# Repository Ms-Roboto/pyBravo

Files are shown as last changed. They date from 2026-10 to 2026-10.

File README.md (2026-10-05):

## In memory of Ben Shamah

This project exists because of Ben Shamah (1973–2018).

Ben studied mechanical engineering at UC San Diego and robotics at Carnegie
Mellon, where he worked on NASA-funded robots built to explore other planets.
He brought that work back down to the bench, joining Velocity11 to build
machines that would speed up medical research — and it was there, with
colleagues including Brad Nelson, Dave Assmusen, and Chris Shaw, that the Bravo
was born. He later co-founded BioNex Solutions and led its technical side.
People who worked with him describe someone quiet and generous, who liked
puzzling out hard engineering problems and liked helping other people solve
theirs even more. He died of cancer in 2018, at 45.

The Bravo is a genuinely good machine, and a lot of them are still running. The 
goal here is to let the hardware Ben helped design join the open source 
community.

---

# pyBravo

An open-source Python driver and web control system for Bravo liquid handling
robots. It connects to the instrument over Ethernet or serial, exposes every
motion and liquid-handling operation through a REST API and a browser UI, and
runs complete pipetting workflows. It has a full simulation mode so you can
build and test protocols without touching hardware.

```bash
git clone https://github.com/kelsorj/pyBravo.git
cd pyBravo
./scripts/start_pybravo.sh      # Windows: scripts\start_pybravo.bat
```

Then open <http://localhost:8000>. Out of the box the server runs against a
simulated robot, so this works on any machine.

> [!WARNING]
> This software drives a physical robot with enough force to break labware,
> crush a pipette head, or injure a hand. Read
> [docs/safety.md](docs/safety.md) before you connect to real hardware, and
> dry-run every new protocol in simulation first.

https://github.com/user-attachments/assets/48de0bf6-f5a1-409d-ab84-00fcac42d9b6

---

## What it does

- **Direct hardware control** — connect, initialize, home, move, and jog every
  axis, with live position and state streaming over WebSocket.
- **Liquid handling** — aspirate, dispense, and mix, with configurable liquid
  classes and pipette techniques.
- **Tips and labware** — tip pickup and ejection, an editable labware catalog,
  gripper pick-and-place, and lid handling.
- **Visual workflow designer** — build protocols as a node graph or describe
  them in a chat that draws a draft graph; review chat drafts in Protocol
  Assistant before simulation and instrument execution.
- **Protocol Assistant** — turn text or PDF protocols into reviewed workflows
  with a local model, resolve missing details, strictly simulate, and reuse
  approved procedures and setups. The [Bravo Capability Manifest](docs/bravo-capability-manifest.md)
  publishes the active instrument's model-selectable planning options and
  compatibility constraints. See [the guide](docs/protocol-assistant.md).
- **Deck management** — a 3×3 deck model with per-location teachpoints, and
  obstacle-aware Z clearance when the gripper carries plates between locations.
- **3D digital twin** — watch a URDF model of the robot mirror the real
  machine's position in real time.
- **Simulation mode** — the full motion, liquid-handling, and workflow stack
  runs with no hardware attached. The optional accessories below are the
  exception: they talk to real serial ports.
- **Optional extras** — camera-based deck verification, barcode reading,
  orbital shaker control, and an LLM-assisted protocol drafter.

## Supported hardware

| Instrument generation | `controller_type` | Connection |
|---|---|---|
| Darwin-generation Bravo | `darwin_native` | TCP, port 7613 |
| Agile 7612 Bravo | `agile_7612` | TCP, port 7612 |
| Bravo SRT | `agile_srt` | TCP, port 7612 |
| Legacy Agile Bravo | `agile` | Serial, or TCP port 10000 |
| No hardware | `simulation` | — |

Details and wiring notes are in [docs/hardware-setup.md](docs/hardware-setup.md).

## Documentation

Start with the [documentation index](docs/README.md). The most-used pages:

| Page | What it covers |
|---|---|
| [Installation](docs/installation.md) | Requirements and install paths for macOS, Linux, and Windows |
| [Quickstart](docs/quickstart.md) | First run in simulation, then your first real move |
| [Hardware setup](docs/hardware-setup.md) | Networking, finding your robot, profiles, teachpoints |
| [Safety](docs/safety.md) | What can go wrong and how to avoid it |
| [User guide](docs/user-guide.md) | The web UI, end to end |
| [Workflows](docs/workflows.md) | Building and running protocols in the designer |
| [Configuration](docs/configuration.md) | Profiles, environment variables, config files |
| [API reference](docs/api-reference.md) | Every HTTP and WebSocket endpoint |
| [Architecture](docs/architecture.md) | How the codebase fits together |
| [Protocol specification](docs/protocol-spec.md) | The instrument wire protocols |
| [Bravo Capability Manifest](docs/bravo-capability-manifest.md) | Versioned instrument options for protocol-planning models |
| [Troubleshooting](docs/troubleshooting.md) | Symptoms, causes, fixes |
| [FAQ](docs/faq.md) | Common questions |

## Requirements

Python 3.11 or newer. The launcher scripts use [uv](https://docs.astral.sh/uv/)
when it is available, which installs a suitable Python and all dependencies
automatically; see [Installation](docs/installation.md) for the alternatives.

## Contributing

Contributions are welcome — see [CONTRIBUTING.md](CONTRIBUTING.md) for how to
set up a development environment, run the tests, and submit a change. Please
also read the [Code of Conduct](CODE_OF_CONDUCT.md). To report a security
issue, follow [SECURITY.md](SECURITY.md).

## License

pyBravo is an independent project. It is not affiliated with, endorsed by, or
supported by Agilent Technologies, Inc. Product names are trademarks of their
respective owners and are used only to identify the hardware this software
runs. See [NOTICE](NOTICE) for the full trademark statement.

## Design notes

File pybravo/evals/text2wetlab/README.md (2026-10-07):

# Text2WetLab OT-2 benchmark adapter

This package generates an Opentrons OT-2 Python API protocol from each task's
written instruction. It uses the configured OpenAI-compatible **local** model
server, validates the Python entry point, and runs `opentrons_simulate` when
that command is available. It never invokes Bravo or Opentrons hardware.

```sh
.venv/bin/python -m pybravo.evals.text2wetlab \
  --task-dir /path/to/task \
  --instruction-file /path/to/task/instruction.md \
  --simulator-command /path/to/opentrons_simulate \
  --event-logger /path/to/pinned/runlog.py
```

An optional `--paper-file` adds task-supplied scientific source text to the
model prompt. For a paper with clear Methods and Results headings, the adapter
passes the complete, verbatim Methods section instead of unrelated article
sections; its trace records the full-source and excerpt digests and line span.
If the section cannot be identified completely, the full supplied text is
preserved. The adapter also reads the installed simulator's labware definitions
and any task-supplied custom JSON to give the model exact well counts and
column layouts. These catalog facts do not supply experimental volumes or
reagents.

Model endpoint and alias default to the existing
`PYBRAVO_DRAFTER_BASE_URL` and `PYBRAVO_DRAFTER_MODEL` settings; the CLI also
accepts `--model-base-url` and `--model`. The benchmark CLI defaults to a
300-second model timeout, 16,000 output tokens, and no automatic repeat of a
timed-out HTTP request. `--model-timeout` and `--max-output-tokens` can adjust
those bounds.
When a task supplies custom Opentrons labware JSON, place the pinned files in
a directory and pass `--labware-dir /path/to/labware`. The adapter passes that
directory to both the CLI simulator and structured logger; the generated
protocol only names the labware in `load_labware()`.

The task directory receives `protocol.py` only after static validation and,
when the simulator is installed, a passing simulation. It always receives
`generation_trace.json` after an attempted generation. Statically valid but
rejected sources remain as `candidate_attempt_N.py` files, with exact paths in
the trace; unchanged repeats skip another simulator run. A trace marked
`static_validated_only` means no simulator was found; it is not a simulation
pass. A `simulated` trace also requires structured action-event validation:
each tip may touch one specimen well before disposal, while a reservoir may
feed multiple wells of an otherwise destination-only plate. A tip may not
aspirate from two distinct reagent-stock wells, and P20/P300/P1000 liquid
strokes must meet the documented OT-2 GEN2 working ranges. For an on-deck
heat-shock/recovery instruction, a timed hot-block pulse must end before
serial recovery pipetting begins. Simulation does
not establish that the protocol satisfies a scientific rubric or is safe to
run on physical hardware.

## Optional phased ActionPlan experiment

`scripts/experiment_text2wetlab_phased_action_ir.py` is an isolated alternative
for protocols too long to fit in one local-model response. The first Qwen call
authors the fixed OT-2 setup, cited initial-supply claims, and a short ordered
stage outline. A separate call authors the actions for each stage. Every
action cites an exact pinned task or paper line. The merger only concatenates
accepted stage actions; it inserts no experimental steps.

Each prefix is compiled against the installed OT-2 catalog, statically checked,
simulated, passed through the pinned event logger and event-safety check, and
audited for tip use and per-well material balance before the next Qwen call.
Unknown starting volumes stay unknown and are reported for review. A failed
prefix stops the experiment; the raw Qwen response and failure remain in the
output directory. The complete merged plan then runs the existing pinned lint,
simulator, event, and local science gates. `official_score` is always null;
Harbor's private scoring is not run. This path never controls hardware or
changes the production generator. The setup trace also lists procedural-looking
source lines omitted from stage citations for review; citations alone never
certify scientific completeness.

```sh
.venv/bin/python scripts/experiment_text2wetlab_phased_action_ir.py \
  --task opentrons-rna-extraction \
  --simulator /path/to/opentrons_simulate \
  --output-dir /tmp/text2wetlab-rna-phased
```

An exact earlier model setup can be resumed with `--saved-setup
/path/to/qwen_setup.json` only when its sibling trace matches the pinned task,
source digests, and raw response digest. `--max-stages` caps further local calls.

## Optional per-well material ledger

`material_ledger.audit_material_flow()` can inspect the trusted logger's
ordered `events` array without changing the generator or benchmark runner.
Pass `WellRef` → `InitialWell` entries for known source volumes and confirmed
empty destinations, plus `WellLimit` entries for catalog capacity or a
scientist-specified final reaction volume. `StageBoundary` and
`stage_targets_ul` let a reviewer check a prepared mixture *before* it is
consumed; this catches a duplicated preparation that a final-volume-only check
would miss. The result retains source-labelled component amounts, final
per-well volumes, ordered snapshots, and separate error/warning codes.

Missing starting volumes remain unknown, and missing destinations are not
silently assumed empty. The logger records only a multichannel anchor well;
callers must provide a geometry-backed `well_resolver` that returns one
`WellRef` per physical channel before multichannel flow is counted. Exact
component amounts for a partial withdrawal from mixed material require an
explicit mix event; a full withdrawal still conserves its total components.
This ledger does not establish reagent identity,
mixing quality, concentrations, or a protocol's scientific correctness. It is
currently a standalone audit utility; it does not change official scoring.

`material_plan_bridge.targets_from_accepted_plan()` can supply ledger targets
from an accepted local-model `PlanningResult`. Because `OT2Plan` has no
destination-well field, each `TargetBinding` must cite the exact vessel/well
and the corresponding reaction volume in the task or paper. For a generated
intermediate, it also needs a matching generated `DeckSource` and a trusted
stage-to-event boundary. Unlinked quotes, ambiguous reactions, and missing
boundaries become `review_gaps`; they never create a target by inference.
Callers can pass the resulting limits, stage targets and boundaries into the
ledger, along with independently confirmed initial volumes and geometry.

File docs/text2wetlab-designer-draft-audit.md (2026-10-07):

# Text2WetLab Designer draft audit

The seven saved Text2WetLab adaptations are local-Qwen-authored **native Designer graphs**. They open with `/designer?workflow=<id>` and use ordinary LiteGraph primitive node types. All seven returned HTTP 200 from the local `/api/workflows/{id}` endpoint on 2026-10-07 with their draft marker and node graph intact. That proves the diagrams can be inspected; it does not prove that their nodes form a valid, simulatable Bravo procedure. Designer now permits software rehearsal of native generated drafts on an isolated simulator, with catalog preflight and a stop on any task error. Hardware Execute remains blocked while `protocol_generated_draft` is true, and rehearsal does not qualify or approve a method. This marker must not be removed to work around validation.

This audit inspected the saved workflows under `~/.pybravo/workflows` against the active `/api/protocols/context` on 2026-10-07. The profile was `04-91-62-CF-7B-B0 / HT_384_D_70`. It offered one execution-ready rack/tip pair: 384-position `lw-4914769d0af7` with independent `st_10ul` tips. Five active classes used `st_10ul`. Two `st_30ul` classes existed, but the context did not offer an execution-ready matching rack. Catalog availability is still separate from confirmation of physical loading or liquid-method qualification.

For unresolved drafts, Designer also offers **Walk through draft** through
`POST /api/workflows/{id}/walkthrough`. This separate, nonexecuting viewer
replays connected task order and retracted head hovers over taught deck
locations. It does not pick tips, move plates, perform liquid strokes, or
validate collision geometry, liquid methods, or scientific completeness.
Every event and response reports `validation_passed=false` and
`qualification_granted=false`. Unknown class references remain visible, and
the strict `/simulate` and hardware `/execute` gates remain in force.

Designer now scopes its class dropdown to the active machine/head (or an
explicit persisted `protocol_simulation_target`). A proposed virtual target
must use catalog head/tip compatibility, capacity, and a known tip length;
it changes only a copied simulator profile. The installed instrument and
hardware class records remain unchanged. Saving retains prior draft findings
with a stale-validation marker instead of displaying a false zero-check result.

| Task | Saved graph | Main blockers for this active Bravo profile |
| --- | --- | --- |
| A1–A12 transfer | [7 nodes](http://127.0.0.1:8000/designer?workflow=10c25e05-4f13-4da6-be02-45f8c233e957), including a 12-iteration Loop | Fixed tip-cell pickup inside the Loop; source and destination labware absent from the proposed deck; 100 µL transfer exceeds the ready ST10 tip capacity; proposed class/rack unavailable. |
| Split 200 µL | [9 nodes](http://127.0.0.1:8000/designer?workflow=b7735e14-79f1-47b2-8560-5469422a0e64) | Two 100 µL liquid actions exceed the ready ST10 tip capacity; proposed 96-position rack and class are unavailable for this head. |
| AMPure cleanup | [42 nodes](http://127.0.0.1:8000/designer?workflow=e41685a4-f7b9-459b-92f2-46c6f45085bd), with separate aspirate/dispense primitives and manual magnet stages | No proposed deck entries at all; liquid locations and tip supply cannot resolve. Several 40–200 µL actions exceed the ready ST10 capacity, and the generic class is unavailable. |
| Colony PCR | [11 nodes](http://127.0.0.1:8000/designer?workflow=236647b7-704b-4b9c-a7cf-1a9339d211d1) | Full 384-channel head mode is proposed against 96-well labware; sample mapping and tip isolation are unproven; proposed rack/class unavailable. |
| E. coli heat shock | [13 nodes](http://127.0.0.1:8000/designer?workflow=c5c9055e-043d-4ad4-b467-9c72d0eca7a1), including external-stage handoffs | Saved review issues include head/plate footprint, missing executable well mapping, and unavailable rack/class. The independent re-audit needs the exact source paper supplied at generation time to verify its saved SHA-256; the default dataset source does not satisfy that digest. |
| Golden Gate | [26 nodes](http://127.0.0.1:8000/designer?workflow=dc69afcd-3825-4340-81ca-3ed769695e6d) | Liquid nodes use a descriptive `wells` string such as `A1:G1`; the Bravo executor reads executable `anchor` and head mode instead. Several transfers exceed ready ST10 capacity; the proposed rack/class are unavailable and sample mapping is unproven. |
| RNA extraction | [25 nodes](http://127.0.0.1:8000/designer?workflow=3530efd6-76b7-4204-94ce-52a9e0d35638) | Full 384-channel mode is aimed at 96-well labware; 48-sample coverage, tip isolation, and elution stage are unproven; proposed rack/classes unavailable. |

These are independent **Bravo** problems. The benchmark's required OT-2 labware, pipettes, modules, and deck slots do not establish matching Bravo consumables or positions. The current profile cannot complete the larger-volume tasks using its one ready ST10 pairing. Switching to or adding a verified head, rack, tip, and method is a hardware-catalog decision; silently splitting a required operation or renaming a method would change the scientific procedure.

## Generic path from a diagram to a usable workflow

1. Have the local model author an ordered, typed scientific action plan with source/destination wells, volumes, sample identities, tip-isolation groups, and external-stage handoffs. Store exact source citations and unresolved experimental facts. Its `wells` list is evidence of intent, not a command to the Bravo executor.
2. Resolve each action against an explicit machine profile and current deck inventory. Require an execution-ready head–tip–rack–liquid-class combination and labware geometry; compare every single stroke with effective capacity. Report unsupported actions instead of creating runnable-looking nodes.
3. Lower resolved actions deterministically to the existing `tips/TipsOn`, `liquid/Aspirate`, `liquid/Dispense`, `tips/TipsOff`, plate, wait, and manual primitives. Expand or parameterize repeated operations so the runtime receives valid `anchor` and head mode for each iteration and fresh-tip selection cannot repeat a spent cell. Preserve the action-to-node provenance.
4. Validate the resulting DAG's topology, per-iteration material and tip ledger, live deck transitions, method settings, and external handoffs. Run strict simulation against the same pinned profile and graph revision. Only a scientist-reviewed, simulation-passing revision should become executable.

To reproduce a **read-only** audit, run `.venv/bin/python scripts/repair_text2wetlab_designer.py --output-dir /tmp/pybravo-text2wetlab-designer-audit`. It writes a report under `/tmp` and never contacts Qwen unless `--run` is supplied. Pass `--ecoli-paper` with the exact original paper if auditing that draft's source provenance. The saved draft remains unchanged.

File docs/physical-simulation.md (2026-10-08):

# Physical rehearsal with SuperDex

Designer **Simulate** and Protocol Assistant strict simulation now run the native
Bravo primitive tasks on an isolated simulation controller. Each controller
motion is checked before positions change. The physical scene uses
[SuperDex Physics](https://projectsuperdex.com/physics/docs/overview/) with closed
Bravo URDF tool/gripper collision meshes, calibrated deck planes, catalog
labware envelopes, and carried plate envelopes. The separate **Walk through
draft** action illustrates order and does not grant physical clearance.

Every Designer **Simulate** action uses the same guarded executor, whether the
protocol was built by hand, imported, loaded from the library, generated by the
assistant, or previously reviewed. Protocol Assistant uses that executor too.
There is no per-protocol physics opt-in. Both entry points call
`WorkflowExecutor.for_simulation(...)`, which requires physical checks, stops on
task errors, and disables the old animation-before-task path. Failed or
unsupported tasks cannot be ignored to obtain a simulation pass.

For a Python caller, construct an isolated `Bravo` with `mode="simulation"`
(copy the hardware profile first), then use
`WorkflowExecutor.for_simulation(bravo, graph, deck_config=deck, on_event=handler)`
and await `execute()`. The ordinary constructor remains the native execution
interface; the simulation factory refuses options that disable required checks.

## Results and saved protocols

A simulation passes only when its final completion event contains a current
SuperDex report with no error and valid checked-move, pose, and contact-query
counts. The report includes
`contract_version: pybravo.superdex-rehearsal.v1`, separately from the native SDK
version. An early scene-ready event is not evidence of completed execution.
Protocol Assistant binds the result to the saved workflow and context hashes;
older passes without this evidence require another simulation. Historical
scientist decisions and approval records are retained for audit.

Changing the robot collision assets invalidates saved simulation evidence.
Changing them during a rehearsal stops that run before another motion is
accepted, so a report cannot silently combine different model versions.

Designer displays the failed task, colliding bodies or missing geometry, and
rejected coordinates. Workflows containing only waits/manual instructions report
that no native motion was checked. **Replay simulation** on a saved compiled
preview replays its recorded events; it does not perform another physical run.

## Installation

In the repository environment, using Python 3.12 on a supported platform:

```sh
python -m pip install -e '.[physics]'
```

The deployment used for this change has SuperDex 1.0.0 installed. Its current
native wheels support macOS arm64, Linux x86_64 and Windows amd64. A missing SDK,
invalid mesh, missing teachpoint or missing collision dimensions causes an
explicit failed rehearsal. It never falls back to unchecked motion. Read-only
planning and the control panel can still load without the optional SDK.

## Planning and tip state

`GET /api/workflows/{workflow_id}/mechanical-readiness` checks the saved native
graph against the selected head and catalog without motion. It reports missing
deck bodies, incompatible selections, and repeated tip-lifecycle errors. This
is a static planning check; strict simulation still checks the actual expanded
loops, runtime inventory, liquid classes and commanded motion.

The native ledger keeps **fresh**, **spent**, **occupied**, and **empty** wells
separate. A returned tip occupies a hole but is spent and cannot be picked as
fresh. The ledger follows moved racks. Only an explicit restock/load resets
fresh supply. In a repeated fresh-tip workflow, the model must plan a clean
supply and a separate compatible empty return rack or configured waste. A
catalog rack is not evidence of loaded inventory. A fixed repeated pickup/return
anchor is rejected; the native runtime also stops on spent pickup, exhaustion,
or occupied return wells. A dedicated source can return its final spent set
to its original rack when that rack will never be used again.

Explicit partial inventories are preserved for catalog racks whose underlying
shape is an SBS plate and whose base class is a tip box. They are not replaced
with a full rack, and the recorded inventory follows the rack when it moves.

The drafter now preserves each proposed rack's `tipbox_fill_state`: clean
supply is full and the separate spent-return box is empty. These are proposed
loading instructions, not evidence of physical inspection. For a gripper-equipped
Bravo, include a visible native DockGripper before tip handling. The native
regression found an undocked finger hitting a rack on a later single-tip pickup;
the same twelve-cycle path clears after docking.

## What is checked

- Axis limits and finite positions; sampled interpolation of every actual
  native controller command, including endpoints and positions between them.
- Tool/gripper contacts with deck pads and labware. A low path through a
  neighboring stack fails even when both endpoints are clear.
- Carried plate envelopes during verified native PickPlace stages, including
  Stack, Destack, Mount and Unmount. Their poses follow the gripper calibration
  and move to their new deck locations after release.
- Mounted tip axes against well centers and bottoms, using recorded tip length,
  well grid, depth and diameter. Intentional rack seating and flange contact
  have narrow task-specific allowances; they do not suppress neighbor contacts.
- Recorded lid exterior envelopes against the moving tool and mounted tip
  segments. A covered liquid target remains inaccessible; native well-access
  checks are preserved rather than commanding an approach through the lid.
- Simulated stack-height scan approach and descent to the catalog-derived stack
  surface. Plate count comes from the virtual deck; optical sensor response and
  force/contact sensing remain unqualified. The scan preserves the modeled
  plate identities for subsequent tasks.
- Drift of profile calibration, teachpoints or labware metadata during the
  rehearsal. Reports pin robot assets, profile and initial deck geometry by
  SHA-256 and retain the failed task, bodies, penetration and sampled pose.

The native SDK runs on one dedicated owner thread. Initialization and disposal
do not freeze the UI event loop; task worker threads synchronously wait for each
collision guard. A rejected multi-axis move leaves all controller positions
unchanged. Errors stop the rehearsal and highlight the task in Designer.

## Limits of a clear result

Designer opens a rotatable obstruction preview for covered-plate failures.
It highlights the reported deck position and stack item, with nearby labware
for context. **View obstruction** reopens the picture; **Edit deck position**
opens the affected setup. Closing the view disposes its renderer, including
assets that finish loading later.

The CellVis 384 plate has a manufacturer-dimensioned lid envelope based on the
[official drawing supplied by the user](media/cellvis-384-plate-lid-dimensions.png):

| Dimension | Millimetres |
| --- | ---: |
| Plate length × width | 127.6 × 85.6 |
| Uncovered plate height | 14.33 |
| Lid length × width × height | 127.15 × 85.05 × 10 |
| Covered assembly height | 16.8 |
| Seated lid bottom above plate base | 6.8 (16.8 − 10) |

Rendering and collision checks use the same centered exterior box. It includes
the hollow interior and undimensioned corner chamfers, so it is conservative;
it can reject close approaches that a detailed shell would clear. The drawing
does not specify wall thickness, internal clearances or grasp calibration.
It therefore supports exterior obstacle checking, not robotic lid removal or
replacement. Existing grasp and departure calibration values are not inferred
from the picture. Delid/Relid remain blocked pending a supported shell/contact
model and verified state transitions.

A liquid task aimed at the covered CellVis plate stops with a dimensioned
well-access diagnostic before its approach is commanded. That picture has no
rejected robot pose. A sampled tool or tip collision with a modeled lid reports
the rejected pose and envelope instead. Unknown lids and seals still stop at
setup and retain the explicitly illustrative preview. None of these views
changes the workflow or marks the lid removed.

The default spacing is 0.5 mm with a 0.05 mm penetration reporting threshold.
These are sampled geometric checks, not certified continuous collision
detection. They interpolate each commanded move in axis space; firmware timing
may differ. The 384ST head uses its collision CAD mesh; other head housings use
a conservative envelope because separate CAD exports are unavailable.

Plate envelopes include solid flanges and approximate well access. Detailed
tip taper, grasp force, fluid retention, calibration accuracy, frame/gantry
self-collision and wet-lab performance are not qualified. Lid operations,
seals, lids without recorded envelopes, and accessories without collision geometry fail
closed. Passing checks does not authorize hardware execution or qualify a
liquid method. The saved revision's method review and release remain required.

Some deployed tip-box records have zero or missing hole diameters. Those records
remain incomplete: static Designer preflight identifies missing return-rack
diameters before motion. It also rejects liquid tasks aimed at a known tip rack
or tip-waste receptacle. Workflows with dynamic locations or deck-changing tasks
retain native checks against the actual labware present at each step.
The simulator does not replace unknown catalog measurements with guessed
clearances. Native tip-cycle regressions use explicitly labeled synthetic
mechanical fixtures; they do not qualify the deployment's rack dimensions.

The deployed `lw-4914769d0af7` ST10 rack's previously missing aperture diameter
was recovered as **3.3 mm** from its existing
`labware/editor_assets/lw-4914769d0af7/ST_Tip_Box.gltf` CAD asset on 2026-10-07.
All 384 circular apertures agree within 0.000003 mm in the exported mesh. Asset
SHA256: `0a9dfef973ae4266042b73614536132d693dc592135c3eccb270d6aa2b082fb5`.
The catalog description records this as model-derived geometry, not a physical
measurement or hardware qualification. Rack height and teachpoint offsets were
preserved. A separate same-plate test workflow uses rack 1 for pickup, CellVis
plate 2 for aspiration and dispense, and empty rack 3 for spent-tip return.

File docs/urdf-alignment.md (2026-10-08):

# URDF head alignment (3D view only)

The original renderer-only calibration below is historical context. The later
[gripper assembly correction](#gripper-assembly-datum-october-2026) updates the
shared URDF used by both the viewers and SuperDex; it does not change commanded
positions or hardware teachpoints.

> **Status: all three axes are fixed.**
>
> - **Z — done.** The head was drawn one teach-tip too low. Corrected via the
>   live `head.teach_tip_length_mm`; see "The Z axis" below.
> - **X and Y — done.** Fixed as measured gantry datums in `JOINT_AXIS_MAP`
>   (`xaxis: 182.64`, `yaxis: 2.3`), not by moving the drawn tips; see "The X/Y
>   datum" below. Two earlier attempts moved the tips instead of the gantry and
>   were reverted — "Two alignments, not one" below explains why that can never
>   work, and remains the most useful thing on this page.
>
> All of this is cosmetic. Real motion is unaffected.
>
> **Confirmation recording:**
> [docs/media/tips-on-off-simulation.mov](media/tips-on-off-simulation.mov) — a
> simulate run captured after the fixes: the head descends aligned with the
> box, the tips leave the box and attach at the bottom of the press, ride up
> with the head, and are released into the destination box at the eject.
> (GitHub plays committed videos from the file's blob page; open the link.)

> **Scope: the 3D view, and nothing else.**
>
> Real motion is correct. Tips on and tips off work on hardware in full, row,
> column and partial modes, on both 96 and 384 heads. The commanded positions,
> the teachpoints, and the geometry in `pybravo/deck/geometry.py` and
> `pybravo/head_mode.py` are therefore **authoritative and out of scope**.
> Nothing described here may change a commanded position, and no change made
> for the reasons in this document belongs anywhere except
> `frontend/src/robot-scene.js`.
>
> If a proposed change to the 3D view would require editing anything under
> `pybravo/`, the proposal is wrong.

## The problem this existed to solve

In the 3D view the head's barrels were drawn a couple of columns away from the
wells they were actually over — worst at the edge of an empty tip box, where
the tips visibly hung off the end.

## The X/Y datum — diagnosed and fixed

The error was in the gantry's visual datum, not in where the tips sit on the
head. Measured with the head-tip array (placed from the head mesh) against the
rendered wells, at four commanded poses spanning 99 mm of X travel and both
deck rows:

| | error, every pose |
|---|---|
| X | **−10.40 mm** (≈2.3 columns), constant |
| row (robot Y) | **+2.40 / +2.19 mm** per location (mean ≈ half a pitch) |

Constant across the whole span in both axes — a datum error, not scale. Both
derivatives measured exactly 1 mm world per commanded mm, so the correction is
a pure `homeOffset` shift in `JOINT_AXIS_MAP` (`frontend/src/robot-scene.js`):
`xaxis` 193.04 → **182.64**, `yaxis` 0 → **2.3**. After the change the residual
is 0.00 mm in X and ±0.11 mm in row at all four poses — the ±0.11 is the two
locations' real taught difference, which a flat model deck cannot represent.

Why this works where the two reverted attempts could not: `homeOffset` moves
the **whole gantry chain** — head mesh, attached tips, and gripper together, as
on the real machine (they share one carriage; confirmed against the URDF joint
tree, where both hang under `ygantry` ← `xgantry`). The tips↔mesh relationship
is preserved by construction (the tips move with their barrel mounts), and
deck pads and labware are static children of the base and do not move. The
earlier attempts moved only the drawn tips, which can satisfy tips↔labware or
tips↔mesh but never both.

The remaining per-location ±0.1 mm class of residual would only be removable by
modelling the deck's taught Z/XY variation, which is not worth it for a
visualization.

This document is the definition the renderer should use instead.

## The invariant

> When the robot is commanded to a position, the **rendered** head's A1 barrel
> must appear at the deck position that command implies — for every head type,
> every labware format, and every head mode.

Equivalently, and more usefully as a test: when a tip operation is commanded
against the A1 anchor of a piece of labware, the rendered A1 barrel sits on the
rendered A1 well.

## Two alignments, not one

This is the trap that has already cost a round of work. There are two
relationships, and a change to the drawn tip positions trades one against the
other:

| | what it means | how it is currently satisfied |
|---|---|---|
| tips ↔ head mesh | the drawn tips sit under the head's visible barrels | correct today, because the tips are placed from the mesh bounding box |
| tips ↔ labware | the drawn tips sit over the wells they are commanded to | wrong today, by the constant above |

Moving the drawn tips can only ever satisfy one of these. Fixing this properly
means establishing where A1 is **in the model**, so both hold at once.

**Any verification must check both.** A measurement that only checks tips against
labware will report success while the tips float away from the head.

## What the backend already fixes for us

Read-only facts, established from the code. These are inputs to the render, not
things to change.

**Barrel grids** — `head_geometry_for_type`, `pybravo/head_mode.py`:

| head type | grid (rows × cols) | pitch |
|---|---|---|
| `HT_384_D_70`, `_S2`, `HT_384_F_50`, `HT_384_PINTOOL` | 16 × 24 | 4.5 mm |
| 96-format (the fallback) | 8 × 12 | 9.0 mm |
| `HT_1536_PINTOOL` | 32 × 48 | 2.25 mm |
| `HT_16_D_ST` | 16 × 1 | 4.5 mm |
| `HT_8_D_LT` | 8 × 1 | 9.0 mm |

**Corner and axis conventions** — pinned by the Head Mode picker, which draws
BACK as −Y, LEFT as −X, and marks the anchor corner at back-left:

- A1 is the **back-left** barrel: minimum X, minimum Y.
- Column index increases toward **+X** (right).
- Row index increases toward **+Y** (front).

**Head A1 offsets between formats** — from the hardware, not from code: the
384 head's A1 barrel sits **2.25 mm left and 2.25 mm back** of the 96 head's A1
barrel. The two grids are concentric at different pitches, so their A1 corners
do not coincide.

## How this was defined in the end

The original plan on this page was a per-head-link constant (`A1_OFFSET`,
placing the barrel array within the head link). The fix that actually shipped
is simpler and sits one level up: the error was the same for the whole gantry,
so it lives in the per-joint `homeOffset` datums in `JOINT_AXIS_MAP`, and the
tips stay placed from the head mesh exactly as before. A per-head constant
would only become necessary if a head's *mesh* were misplaced within its own
link — no evidence of that once the gantry datum was corrected.

If a future head model does need a per-link constant, the measurement
procedure is unchanged: command the A1 anchor over a known box, read where the
mesh's barrels render versus the wells, at two distant locations (the value
must be constant), and for the 96/384 pair check their difference comes out at
(2.25, 2.25) — the two grids are concentric at different pitches.

## Verification

A fix is only complete when all of these hold:

1. **tips ↔ labware**: the rendered A1 barrel sits on the rendered A1 well when
   commanded to the A1 anchor, for both head formats.
2. **tips ↔ head mesh**: the rendered tips sit under the head mesh's own
   barrels — checked visually and by comparing tip positions against mesh
   barrel positions.
3. **Pose independence**: both hold at several positions across the deck, not
   just the one used to derive the constant.
4. **Mode independence**: both hold for full, row, column and partial modes.
5. **`git diff --name-only -- pybravo/` is empty.** No Python changed, so no
   commanded position can have changed.

## The Z axis — diagnosed and fixed

The head rendered one **teach tip** too low, at every Z.

Robot Z is referenced to the tip of the teach tip, not to the barrel face: the
backend computes `deck_surface_z = teach_z + teach_tip_length`. The renderer
placed the head as though Z meant the barrel, so it sat low by exactly that
length.

Measured against the deck surface, head mesh only, with the synthetic tips
excluded — they are children of the head link and contaminate the measurement
if included, which is how an earlier pass produced a spurious 44.1 mm:

| | before | after |
|---|---|---|
| loc 1 (50 mm box), Z = 0, 50, 100, 115.1, 140, 165.1 | −26.14 mm at every Z | **−0.04 mm** |
| loc 4 (25 mm box), Z = 0, 50, 100, 115.1, 140, 164.9 | −25.94 mm at every Z | **+0.16 mm** |

Constant across Z, independent of labware height, and −26.04 mm on average
against a nominal `teach_tip_length_mm` of 26.1. The residual ±0.1 mm is the
0.20 mm difference between the two locations' taught Z, which a flat model deck
cannot represent — it is real machine variation, not modelling error.

The fix uses the `homeOffset` mechanism already present in `JOINT_AXIS_MAP`,
which at the time was calibrated for X (193.04 — since re-measured to 182.64,
see "The X/Y datum" above) and Zg (−20) but left at 0 for Z. The value
is taken live from `head.teach_tip_length_mm` on `/api/profile` rather than
hardcoded, so a different head or teach tip follows automatically, with the
common 26.1 seeded as a fallback.

Two things were checked because they could have been broken silently:

- **Tips still sit on the head.** The whole head link moves, so the
  barrel-to-tip relationship is preserved by construction — unlike the X/Y
  attempts, which moved only the drawn tips. The old 17.9 mm rendered ST10
  extension was later found to be 2 mm short; see the correction below.
- **The gripper did not move.** `zaxis-gripper` is coupled to Z, so it could
  have been dragged along; measured at 87.8 mm before and after, unchanged.

### `tip_offsets.yaml` was never the problem

Worth stating plainly, because it is the intuitive place to look. The backend
already resolves `config/tip_offsets.yaml` and folds the result into the
commanded Z: `deck_surface_z - labware_height`, then the eject offset. Moving
between the Tips On and Tips Off poses raised the head by exactly 14.2 mm in the
view, which is `tips_off_z_offset: 14.0` arriving intact.

**Those offsets are therefore already in the Z the renderer receives, and must
not be applied again there — that would double-count them.** What the view was
missing was the datum, not the offsets.

### A more durable version of this fix

The backend computes `deck_surface_z` in the tips motion path (`executor.py`)
but does not send it to the frontend. Sending it would let the renderer derive
the Z datum from the deck directly, rather than reconstructing it from the teach
tip length. Worth doing if this ever drifts again.

## Open questions

- The X/Y/Z datums were measured with the 384 head model. If a 96-head mesh is
  ever added to the URDF, re-run the four-pose sweep with it — the gantry
  datums should hold (they are properties of the gantry, not the head), and any
  residual would indicate the new head mesh is misplaced within its link.
- The datums are tied to this revision of the URDF. If the URDF is re-exported,
  re-measure — the sweep takes minutes and the procedure is above.

## Notes for whoever picks this up

The renderer currently falls back to `_getHeadTipMountFrame` whenever it lacks
better information, which is the right shape — keep a fallback so the tips are
always drawn somewhere sane, and prefer the defined constant when available.

Be aware that the designer pauses the `/ws/state` socket while a simulation runs
(`setSimulationMode`), so anything the renderer needs from server state must not
depend on that socket being live. A previous attempt at this fix was correct but
never executed for exactly that reason.

## Visual appearance

The URDF carries the Bravo's off-white covers, graphite frame, metallic tooling, PEEK-tan barrels,
and nine pad colors: pads 1–3 are blue, 4–6 green, and 7–9 yellow, with
three shades per group.
Both web viewers read these colors through `frontend/src/robot-appearance.js`,
which supplies the surface roughness and metallic response.

`python scripts/build_bravo_skin.py` regenerates the `bravo_*.stl` visual
surfaces and markings from the original meshes. The finish boundaries preserve
the original surface area and bounds; the original collision meshes, joint
frames, inertias, and calibrated datums are unchanged. After a CAD re-export,
review those boundaries before regenerating the visual assets.

With the web server running, `/static/bravo-preview.html` opens an orbitable
preview with perspective, front, and isolated-deck views. This page does not
connect to the robot's state socket or send motion commands.

## Gripper assembly datum (October 2026)

The exported gripper assembly floated to the right of the head. Its carriage
had a **12.40 mm air gap** from the housing and its outer edge extended
**29.40 mm** past the housing. This placement preceded the realistic materials
update: that update split the original surfaces without changing their bounds.

The user's real Bravo photograph and Agilent's
[gripper assembly illustration](https://automation.help.agilent.com/AutomationSolutionsKB14/Bravo%20User%20Guide/images/00263d_bravo_with_gripper.png)
show the carriage immediately alongside the head. The photo establishes the
arrangement, not a millimeter calibration. The correction comes from the
existing CAD contact pads and the native pickup position:

- Each finger has two inward-facing pads, at local X −108…−100 mm and
  −74…−66 mm. Their combined center is −87 mm in the finger mesh.
- After the existing joint transforms, both pad pairs were centered at
  **X +71.746546 mm** relative to the commanded native pickup X.
- Native PickPlace uses the recorded deck X teachpoint. The center of a
  standard 96-well plate is **X +49.5 mm** from this datum. The 384- and
  1536-well grids have the same center after their A1 offsets are included.
- Moving the whole gripper assembly **22.25 mm toward −X** places both pad
  pairs at **X +49.496546 mm**, a 0.004 mm residual from exported-mesh rounding.

Only the `zaxis-gripper` origin X in the shared URDF changes, from 0.100478 m
to 0.078228 m. The carriage and both fingers move together. The commanded
axes, head/barrel position, finger spacing and travel, Zg dock datum, and native
PickPlace calculations remain unchanged. Both web viewers and SuperDex consume
the same corrected joint, and the collision asset digest changes with it.

The corrected carriage has no lateral air gap and extends **7.15 mm** past
the head's bounding edge. This is the existing CAD assembly aligned to its
grasp datum, not a dimensional certification inferred from a photograph.
`tests/test_physics_asset_scene.py` checks the actual transformed contact flats
against the native plate centers in all three grid formats.

## Mounted tip length and Cellvis well geometry (October 2026)

The mounted-tip renderer previously subtracted 2 mm from the recorded tip
length as an artificial mounting overlap. That drew the ST10 outlet 17.9 mm
below the barrel even though its recorded length is 19.9 mm. The rendered
barrel-to-outlet distance now uses the complete recorded attached-tip length,
matching the native Z calculation and the collision scene. A visual overlap
must not shorten that distance or introduce another motion offset.

The Cellvis P384-1.5H-N plate also needs a well model rather than a solid box.
The shared asset at
`labware/editor_assets/lw-34358f93e2a0/Cellvis_P384_1.5H_N.glb` is generated by
`scripts/build_cellvis_plate.py` from the manufacturer's
[dimension drawing](https://www.cellvis.com/images/glass_bottom_plate_384_well_size.png)
for the [P384-1.5H-N plate](https://www.cellvis.com/product_detail.php?product_id=53).
It is a dimensional reconstruction, not a vendor CAD export.

The drawing establishes a 127.6 × 85.6 × **14.33 mm** plate with **11.38 mm**
inside well depth. The inside glass surface is therefore **2.95 mm above the
deck datum**; the 0.17 mm cover glass extends below that surface. The 16 × 24
grid has 4.5 mm pitch and tapered square openings, **3.7 mm across at the rim**
and **3.3 mm across at the glass**. All 384 wells are open in the asset, with
the glass at the inside-bottom plane rather than a solid surface at the rim.

Both the editable catalog and its runtime snapshot use those outer dimensions
and depth. The catalog's 3.3 mm aperture is a conservative inscribed circle
within the square opening for the current radial clearance checks; it is not
the visible rim width. Physical A1 is **12.05 mm / 9.05 mm from the outside
plate edges**. The catalog's **2.25 mm / 2.25 mm offsets** instead reference
the machine's taught 96-well A1 datum. These are different coordinate origins
and must not be substituted for each other.

`tests/test_cellvis_visual_geometry.py` intersects vertical rays with the
shipped asset: every well center and an interior square corner must reach the
glass, a ray through the taper must intersect the wall at the expected height,
and a ray outside the opening must hit the rim. It also checks the glass
thickness and the asset dimensions against both catalogs.

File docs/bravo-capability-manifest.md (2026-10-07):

# Bravo Capability Manifest, version 0.3

The Bravo Capability Manifest (BCM) gives a protocol-planning model a finite,
typed set of choices for the **configured** pyBravo instrument. It describes
what an assistant can propose, which robot operations pyBravo can compile, and
which catalog resources may be selected. It is discovery data, not a command
interface or permission to operate hardware.

The normative JSON Schema is
[`schemas/bravo-capability-manifest-v0.3.schema.json`](../schemas/bravo-capability-manifest-v0.3.schema.json).
The [example](../schemas/examples/bravo-capability-manifest-v0.3.example.json)
shows a 384ST simulation profile. Versions 0.1 and 0.2 remain available in the
same directories for consumers of the earlier formats. The identifier
`schema_version: "0.3.0"`
describes this document's format; it is independent of the `ProtocolPlan`
schema version and the instrument's firmware or controller protocol.

`GET /api/protocols/capabilities` returns the active profile's read-only
manifest. Fetch it again after changing the head, profile, labware catalog,
tips, or liquid classes. Protocol Assistant sends a bounded subset of these
choices to the local model and checks returned action IDs against it; the
full endpoint is useful for external planners and catalog review.

`method_registry` points to `GET /api/protocols/methods` and typed
`POST /api/protocols/methods/lookup`. Its digest and status counts let a client
detect changes without copying method settings into the manifest. The lookup
endpoint is read-only: it ranks applicable methods and reports evidence and
mismatches; it cannot edit settings or authorize hardware execution. The
method record and its referenced liquid class hold numeric pipetting settings.
`catalog_summary` reports static catalog status and provenance, not physical
deck contents or method qualification. See [Bravo method knowledge](bravo-method-knowledge.md)
for the separation of catalogs, method records, skills, recipes, and inventory.

`spent_tip_exclusion` and `physical_collision_rehearsal` distinguish inventory
correctness from geometry checking. Before rehearsal, external planners can
inspect `GET /api/workflows/{workflow_id}/mechanical-readiness` for static
catalog/deck and repeated-tip diagnostics. Designer Simulate runs the native
motion with [SuperDex collision checks](physical-simulation.md); a visual
walkthrough provides no physical clearance or release approval.

## Model Hardware Standard relationship

[Anthropic's Model Hardware Standard (MHS)](https://www.anthropic.com/news/model-hardware-standard-research-preview)
is in a research preview, and its schema is not yet public. BCM is a pyBravo
format designed for Bravo protocol planning. It does not claim MHS conformance.
When an MHS schema becomes available, a separate adapter could map these
capabilities into it without changing pyBravo's hardware validation.

## Document model

The server derives a manifest from its active machine context. A conforming
producer MUST publish these top-level fields:

| Field | Meaning |
| --- | --- |
| `standard`, `schema_version` | Format identity and semantic version. |
| `context_hash` | Digest of the profile and catalogs used to make these choices. A plan MUST be checked against current context before compilation. |
| `machine` | Configured head ID, channel geometry, and whether a gripper is configured. A head's numeric model name is **not** a tip-selection rule. |
| `assistant_operations` | High-level, model-selectable `ProtocolStep.kind` choices with typed parameters, preconditions, effects, availability, and deterministic lowering targets. |
| `robot_operations` | Compiler-allowlisted graph node types. These are for explanation and auditing; their presence never makes them directly selectable by the Protocol Assistant. |
| `tipbox_choices` | Exact, catalog-backed rack **and** tip pairs for this head. The rack and loaded tip retain independent identities. |
| `tipbox_catalog_candidates` | Plausible incomplete rack records for catalog maintenance, never verified choices. |
| `tip_plate_compatibility` | Exact tip ID to catalog plate ID planning rules, including explicit incompatibilities. These rules do not qualify a run. |
| `labware`, `tip_definitions`, `liquid_classes` | Compact catalog entries with stable IDs and known values. A listed entry does not establish physical presence on the deck. |
| `labware[].dead_volume_ul`, `labware[].dead_volume_status` | A plate's catalog starting estimate and whether it is `reviewed` or an unreviewed `placeholder`. The value does not establish the residual for a particular liquid, tip, or aspiration method; the protocol planner requests scientist confirmation before using a placeholder for a source. |
| `catalog_summary` | Counts by catalog status, with provenance of the configured stores. `identity_complete` for a liquid class means its machine, head and tip identifiers exist; it does not mean the class has been calibrated. |
| `method_registry` | Version, digest, status counts, and discovery URLs for the separate method library. No motion setpoints or asserted live inventory are embedded. |
| `setup_decision_rules` | Conditional, evidence-tagged recommendations for setup fields. These are planning suggestions, not completed scientist decisions. |
| `constraints`, `review_requirements` | Stable rule IDs and human-readable explanations. The server enforces rules; the descriptions help a model ask useful questions. |

`setup_options` offers the protocol setup's tip strategies, disposal policies,
and head modes as explicit IDs. A `requires_reason` or
`requires_confirmation` flag is a prompt to collect a scientist's decision,
not a model decision. The `waste_container` disposal option has
`value_kind: "material_id"`: the chosen `tip_disposal_id` must be an actual
material with role `waste`, placed on the deck. The mode name itself is **not**
a valid `tip_disposal_id`. `return_to_source_rack` has
`value_kind: "literal"` and is the only literal disposal value in this
version; it requires the `fresh_each_source` strategy and confirmation that
spent tips will not be selected again. Head-mode options list the fields that
must be supplied and still require confirmation and exact rack–tip footprint
validation. `transfer_patterns` contains geometry-backed mapping
options. For a compatible 384-channel head and cataloged 384/1536 plates, it
lists source anchor A1 and destination anchors A1, A2, B1, B2. The `status`
value `geometry_option` means a shape that can be reviewed; it is not evidence
that the physical plates, teachpoints, or liquid class are suitable.

## Setup decision rules

`setup_decision_rules` gives an assistant a small rule language for the setup
fields that otherwise require automation-engineer judgment. Each rule names a
JSON-pointer `decision`, a conjunction of typed fact predicates in `when.all`,
and a `recommendation` or `null`. A predicate supports `eq`, `gte`, or `in`.
Consumers MUST establish every required fact from the current reviewed plan
and its source evidence before applying a rule. A missing or ambiguous fact is
**unknown**, not `false`. Rules are advisory even when their
`evidence_level` is `derived`; the validator and scientist still check the
result. In particular, an assistant MUST NOT turn a rule's `required_evidence`
text into a purported scientist answer.

| Evidence level | Meaning |
| --- | --- |
| `derived` | The suggested value follows deterministically from verified plan facts and configured geometry. This does not verify physical setup. |
| `heuristic` | An engineering option fits the stated facts but needs a contamination, inventory, or physical-layout review. |
| `scientist_input` | No value is recommended. The scientist must provide or approve a procedure-specific value. |

The plan-fact vocabulary is deliberately narrower than natural language:

| Fact | Meaning |
| --- | --- |
| `liquid_step_count` | Number of planned transfer or mix intents after expanding bounded repeats. |
| `full_head_footprint` | Cited all-wells instructions or a narrowly matched four-source quadrant plan support a full-head proposal on verified grids. A plate's well count or anchor alone is insufficient; free-text evidence remains a heuristic until the scientist confirms this exact plan. |
| `source_count` | Distinct source materials addressed by liquid steps, in first-use order. |
| `dedicated_tip_rack_per_source` | The plan has one distinct tip material per source, and each selected rack–tip pair is exact and catalog-compatible with the active head. This does not establish actual tip inventory. |
| `st10_384_dedicated_racks` | Every source has an exact, execution-ready 384 ST10 rack–tip catalog pair. |
| `destination_initially_empty` | Every destination well addressed by the proposed reuse pattern has a recorded initial volume of zero, and source footprints on each destination do not overlap. Unknown volumes or overlapping source footprints do not satisfy this fact. |
| `destination_footprints_disjoint` | Different sources address separate destination wells under the proposed full-head mapping. This does not establish that those wells start empty. |
| `no_recorded_destination_liquid` | The draft records no nonzero starting liquid in either destination. A missing volume is still unknown, not confirmation of emptiness. |
| `four_source_quadrant_recipe`, `four_source_five_ul_pairings` | Cited source text and the exact plan describe four 384 sources, two 1536 destinations, eight quadrant transfers, and two 5 µL transfers per source. |
| `same_source_reuse_prohibited` | A scientist decision or explicit instruction requires fresh tips between the two destinations. |
| `same_source_reuse_authorized` | A scientist decision bound to the current plan allows a dedicated set to dispense from one source into the planned destinations. Empty destination plates by themselves do not grant authorization. |
| `tip_strategy` | A saved choice or an earlier advisory proposal in the same resolver response. Cascaded proposals remain unconfirmed until the scientist reviews them. |
| `waste_material_present` | The plan contains an on-deck material with role `waste`; an unplaced catalog entry does not count. |
| `minimum_addressed_well_depth_mm` | Minimum positive catalog depth among all addressed plates, when all depths are known. Used only as an exclusive upper bound on pipetting height. |

For a full-head 384-to-1536 quadrant candidate, the rule recommends
`{subset_type: all_barrels, subset_config: back_left}`. The full head's 16×24
channel count comes from configured geometry; `row_count` and `column_count`
remain `null` in setup. A source phrase or model interpretation provides a
heuristic proposal; only a scientist decision bound to that plan supplies
derived scope evidence. If the intended footprint is partial, the model must
ask for the shape and corner rather than choose an arbitrary quadrant of the
head. The `tip_rack_order_by_source` rule uses a fixed
`source_ordered_verified_tip_rack_ids` resolver: a consumer may fill this only
when each source has an unambiguous link to one exact, distinct, catalog-
compatible tip material, then list those racks in source first-use order.
An explicit scientist mapping is derived evidence. A rack ID containing the
exact source ID is a heuristic proposal that requires confirmation. Material
list order and fuzzy name similarity do not establish a link.

The source-dedicated tip rule suggests `fresh_each_source` when the
scientist explicitly permits same-source reuse, each source has its own
compatible rack, and addressed destinations are recorded empty. A second,
narrow rule offers the same strategy as a **conditional draft** for the cited
four-source 384-to-two-1536 ST10 pattern, even when destination starting
volumes have not yet been recorded. It requires the scientist to confirm that
both destinations start empty and that the dispense method avoids unacceptable
carryover. Two 5 µL dispenses fill the nominal 10 µL tip capacity, so this
proposal retains two separate aspirations unless a reviewed method establishes
enough effective capacity for a shared aspiration. Neither rule authors
`tip_reuse_reason`; the contamination assessment remains open. The resolver
may use a proposed strategy to offer a rack order and disposal choice in the
same response, but it does not save any of them. If the scientist explicitly
rejects reuse,
`fresh_each_step` is a possible strategy subject to enough fresh tips. With
source-dedicated racks and no waste material, the return rule may suggest the
literal `return_to_source_rack`, provided used tips return to their original
wells and are never reselected. A waste receptacle instead requires its actual
on-deck material ID. These conditions are not claims that racks are stocked or
that waste capacity is sufficient.

The manifest identifies only active machine classes. In simulation,
`POST /api/protocols/liquid-class-proposals` may present explicit head/tip
classes from another local machine as non-executable planning references,
with source settings and unresolved applicability. It never makes a
cross-machine class an active catalog option.

Pipetting height is never guessed from plate depth. Its rule publishes the
only generic bound supported by the catalog and validator:
`0 <= distance_from_bottom_mm < minimum_addressed_well_depth_mm` when all
addressed well depths are known. The approved height, liquid class, and reuse
assessment remain scientist inputs because they depend on the reagent,
geometry, tip, volumes, and qualified method.

All dimensions and quantities carry unit-suffixed keys or an explicit `unit`.
Volume is in µL, position in mm, and duration in seconds unless a parameter
declares another unit. Unknown numeric values MUST remain absent or `null`;
zero is a measured value, not a substitute for unknown. A consumer MUST use
IDs for selection rather than matching names, prefixes, or capacity numbers.
It MUST ignore unknown namespaced extensions for planning and MUST NOT turn
unrecognized extension values into robot commands.

`context_hash` describes configuration, not momentary state. Tip inventory,
mounted tips, deck occupancy, connection status, and live axis positions can
change while a manifest is displayed. A producer MUST NOT use a cached
manifest as proof of those conditions. At compile time, pyBravo rechecks the
current profile, catalogs, setup, recorded inventory, proposed deck, and all
validation rules; the scientist confirms physical state before a run.

## Intent versus robot operation

An **assistant operation** is a scientific planning intent. `transfer` means
one source-to-destination movement and lowers to a distinct `liquid/Aspirate`
followed by `liquid/Dispense` at the same volume. `distribute` addresses one
source and an ordered list of destination/volume pairs. It lowers to one
aspiration followed by ordered, distinct dispenses only when the selected
method, effective tip capacity and calibrated command volumes permit it.
Otherwise the compiler uses separate aspiration/dispense pairs when safe, or
reports a validation error. A consumer MUST NOT
assume that `lowers_to` is a fixed node count: it lists node *types*. The
reviewed DAG shows every actual aspiration and dispense.

`selectable: true` means the Protocol Assistant has a plan representation for
that intent. `availability` reports the active profile's coarse status:
`available`, `requires_setup`, or `unavailable`. Neither field means the
specific run is qualified. The server still checks the selected materials,
head mode, calibrated liquid class, confirmed volumes, tip inventory,
teachpoints, stack clearance, and instrument state. A configured machine with
no gripper, for example, can describe `move_plate` but MUST mark it unavailable
for automated planning. Unsupported scientific actions become explicit manual
steps; they do not disappear from the protocol.

`robot_operations` describes compiled graph node types and is not an LLM tool
list. Each robot operation has `model_selectable: false`, even when the graph
node is available to the deterministic compiler. A model MUST return a
reviewable protocol plan with operation IDs and
source evidence, never raw graph nodes, device packets, Python code, or a
claim that its own selections have been approved.

## Resource compatibility and qualification

A selectable tip combination MUST have an exact rack-to-tip catalog link,
head-compatible tip definition, and compatible rack geometry. For example,
the current catalog records both `st_10ul` and `st_70ul` for 384ST rack
`lw-4914769d0af7`. The rack name or its default tip does not choose which
tips are loaded. The head ID `HT_384_D_70` also does not require 70 µL tips.
`execution_ready` on a pair means its static metadata is complete enough to
offer as a candidate; it does not certify that a physical rack contains those
tips or that a particular liquid class and plate are qualified.

`tip_plate_compatibility` is a separate relation because tip-to-head and
rack-to-tip compatibility do not imply suitability for every plate. Each row
names a `tip_definition_id`, a contacted `target_labware_id`, its well count,
and the contact roles in `applies_to` (`source`, `destination`, or `mix`). A
`planning_compatible` row permits **drafting** only and always has
`execution_ready: false`; it does not establish a calibrated dispense,
physical clearance, alignment, or tip inventory. An `incompatible` row tells
the planner to exclude that exact tip/plate pairing, even when the tip fits
the head and rack. Missing rows mean **unknown**, never compatible by default.
The runtime validator remains authoritative if a catalog row or profile
changes.

Some catalog entries are intentionally provisional. The 96ST visual model
`lw-96st-provisional` has no approved tip links and MUST stay outside
`tipbox_choices`. It may appear in `tipbox_catalog_candidates` with an
explanation of missing evidence. A missing tip length, plate well capacity,
calibration, or source volume MUST create a review requirement rather than an
invented value. Plate compatibility can be more restrictive than head and rack
compatibility: Agilent's
[384ST 10 µL overview](https://www.agilent.com/cs/library/technicaloverviews/public/te-bravo-automated-liquid-handling-384st-10-ul-tip-5990-3645en-agilent.pdf)
supports ST10 tips with 1536-well plates and excludes ST70; the validator
enforces that distinction for the current workflow.

The manifest is a **starting dictionary**, not a substitute for the catalog
or a record of scientist approval. The scientist confirms physical deck items,
tip type and freshness, well volumes, mapping, liquid class, and relevant
clearances. Validation and strict simulation precede any executable export.

## Producer and consumer rules

1. A producer MUST generate choices from the active machine profile and
   authoritative catalogs; a model response cannot amend capabilities.
2. A producer MUST give each action and rule a stable ID. `preconditions` and
   `effects` refer to named rules or state concepts rather than executable
   expressions. Natural-language descriptions are explanatory, not the source
   of truth for validation.
3. A consumer MAY rank valid choices or propose values, but MUST preserve
   unknowns and cite the scientist's source text for quantitative steps.
4. The server MUST validate the proposed plan against current context and
   reject stale IDs, incompatible rack-tip-head-plate combinations, stale
   method versions, and unresolved setup. Simulation and scientist approval
   are separate gates.
5. A producer MUST NOT set `execution_ready: true` for provisional pairs or
   infer missing associations from a rack name. A consumer MUST NOT promote a
   catalog candidate into a selectable pair.
6. A change to field meaning or required structure increments the minor or
   major schema version. Additive optional fields increment the minor version;
   incompatible changes increment the major version. Consumers MUST reject an
   unsupported major version rather than guessing its semantics.

JSON Schema validates shape and basic types. Cross-field identities, catalog
membership, physical geometry, well accounting, and tip lifecycle are checked
by pyBravo's deterministic validator, not by JSON Schema or an LLM.

The checked-in example is a static snapshot from `profiles/simulation.yaml`.
It has no liquid class for machine ID `SIMULATED`, so its operations illustrate
planning choices rather than a runnable configuration. Regenerate it only
from a deliberately selected profile and validate it against the checked-in
schema; do not capture connected instrument state in the example.

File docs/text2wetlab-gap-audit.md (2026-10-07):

# Text2WetLab gap audit: scientific plans before code

This is an independent local audit of the seven pinned Harbor tasks at dataset revision
`d7c8a9b93428997447eeaf2ee9e27ac3ce026872`. It is **not an official score**. The
task instructions, supplied papers, and saved Qwen candidates are evidence; the public
grader rubrics are used only to inspect coverage, never as model-generation instructions.
No protocol answer is written here.

| Task | Current local observation | General gap |
| --- | --- | --- |
| A1–A12 transfer | Four observable checks supported; fidelity needs review. | Verify comments and absence of outcome-changing extra steps. |
| Split transfer | Four observable checks supported; fidelity needs review. | Preserve one 200 µL aspiration feeding two 100 µL dispenses. |
| AMPure cleanup | Core transfer volumes and 96-well mapping supported; manual stages and stock backflow need review. | Represent manual magnet/drying handoffs and per-tip liquid contact. |
| E. coli heat shock | Measurable transfer/module sequence supported; paper fidelity needs review. | Compare all executed stages and comments to the cited method. |
| Golden Gate | One local category supported, two failed, two need review. | Enforce reaction stoichiometry and an ordered, parameterized handoff timeline. |
| Colony PCR | A newer Qwen candidate passes the local simulator and pinned run log, but still needs scientific review. | Resolve the unspecified primer stock concentration and require a real operator handoff before each permitted tip-rack refill. |
| RNA extraction | No accepted simulator run. | Plan by pipette/tip capacity, eight-channel column geometry, and sample isolation before code. |

The saved Golden Gate protocol at
`/private/tmp/pybravo-text2wetlab-golden-planning/golden-gate-assembly/protocol.py`
dispenses 20 µL premix, 2.5 µL of each primer, and 1 µL template into each PCR well:
**26 µL total**. The supplied Methods specify 25 µL PCRs, 0.1 µM each primer, and
0.5 ng linearized template. The fixed task inventory lists 1 µM primers and
0.5 ng/µL template. From those cited values, a general concentration/volume solver
derives 2.5 µL of each primer, 1 µL template, and **19 µL remaining** for premix.
The model's PCR handoff also says only “run PCR program,” omitting the supplied 98 °C
initial denaturation, 34–36 cycles, and final extension. The local audit in
`pybravo/evals/text2wetlab/rubric_audit.py` catches the per-well volume and missing
program note but does not verify mixture composition or the chronology of all manual
handoffs. A newer direct Qwen candidate prepared the same master mix twice in the
same initially empty rack well; a reminder to emit only final code did not prevent it.

An earlier colony PCR candidate correctly stated that its P20 stages need 193 pickups
from one 96-tip rack, but reset only after the 96-primer loop. One earlier master-mix
tip meant the 97th pickup failed **inside** that loop. It also treated 3.5 µL of absent
water as a manual addition, leaving the robot with only 7 µL in a nominal 10 µL
reaction. The fixed inventory does not list water or a premixed 1× source. A newer Qwen
candidate instead simulates 5 µL of 2× Q5 mix, 4 µL of the matching primer-pair solution,
and 1 µL of colony template per well, with rack resets before tip exhaustion. Its own
comments acknowledge that primer concentration is unknown, so 4 µL cannot yet be judged
chemically suitable. It reports a refill by comment and calls reset_tipracks(), but does
not pause for the operator to load fresh tips. Simulation success does not resolve either
gap. The paper's 9 µL master mix plus 1 µL colony template is a method description; the
task's fixed stocks require a feasible, explicitly justified adaptation, never an
undocumented substitution or a false claim in comments.

The RNA candidate consumes its 96 P1000 tips on 48 bead and 48 isopropanol additions,
so it fails before the first sample pickup. It later passes lists of eight wells to
single-location multichannel calls, attempts 100 µL recovery from each 100 µL elution,
and uses P1000 strokes below the stated 100 µL minimum. The task has three 96-tip
P300 racks: 36 eight-channel pickups. Its 200 µL tips cap each P300 stroke at 200 µL.
A valid plan must distinguish shared-reagent, noncontact dispensing from tips that
have touched distinct samples; it should retain a tip set within one sample column
across split removal strokes when safe, and count every pickup by phase. The paper
states 100 µL elution buffer but no exact recovery yield, so the knowledge layer
must record an experimentally reviewable residual/recovery assumption rather than
pretend the paper supplied a number.

## Reusable implementation contract

1. Have the local model produce a **cited, typed stage plan** before executable code.
   The plan names each starting vessel, generated intermediate, per-well additions,
   source/destination mapping, manual handoff, module state, and tip policy. Keep
   benchmark rubrics outside the model prompt.
2. Deterministically solve each reaction's volume and stock-to-final concentration
   equations. Trace generated mixtures as material states, not just vessel names.
   Reject missing components, duplicate preparations, overfilled reactions, and
   comments that claim an unexecuted fix. Preserve unresolved quantities as review
   questions; do not manufacture a scientific fact.
3. Build an ordered event ledger from the simulated run: reagent-to-well transfers,
   actual mixing cycles, module transitions, delays, and manual handoffs. Compare
   the ledger to the cited plan, including **stage order and parameters**, rather
   than only searching comments for words. A manual pause is an asserted operator
   handoff for the OT-2 benchmark, not proof of physical completion on Bravo.
4. Preflight tip availability at each pickup, including loop boundaries and
   multichannel consumption. Include effective capacity from the installed tips,
   not only the pipette name. Permit refill/reset only with task authorization and
   a physical handoff at exhaustion. A simulator error then points to the precise
   resource-plan discrepancy instead of prompting a full regeneration.
5. Track per-tip contact provenance. Reusing a clean tip for a shared reagent is
   safe only when destination dispenses avoid contact; after sample contact, reject
   another specimen or shared-stock entry. Check physical well shapes and channel
   pitch before allowing multichannel moves.

The current typed plan (`pybravo/evals/text2wetlab/planning.py`) already has reactions,
sources, stages, tip budgets, and source quotes, but it does not compile ordered
per-well actions. The current audit (`rubric_audit.py`) checks many endpoint facts but
leaves mixture ancestry, manual chronology, and stock backflow to review. A generic
plan-to-action compiler plus these validators is the shortest path to reproducible
coverage. It must stay separate from Bravo execution: OT-2 task decks and modules
do not become physical Bravo capabilities merely because an OT-2 draft simulates.

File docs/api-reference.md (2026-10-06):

# pyBravo HTTP & WebSocket API Reference

pyBravo exposes a FastAPI backend (`pybravo/web/server.py`) that drives Bravo liquid-handling
robots, manages deck and labware configuration, stores profiles, and runs the workflow designer.

- **Base URL:** `http://localhost:8000` (the server binds `0.0.0.0:8000` by default; see `run_server()`)
- **Interactive docs:** `http://localhost:8000/docs` (Swagger UI), `http://localhost:8000/redoc`,
  raw schema at `http://localhost:8000/openapi.json`
- **CORS:** all origins, methods, and headers are allowed.

## Content types

| Direction | Type | Used by |
|---|---|---|
| Request | `application/json` | Most `POST`/`PUT`/`PATCH` endpoints (Pydantic models) |
| Request | `multipart/form-data` | File uploads (labware assets, PDF and JSON imports) |
| Request | query string | A handful of endpoints take scalars as query parameters — noted per route |
| Response | `application/json` | Default for every `/api/*` route |
| Response | `text/html` | Page routes (`/designer`, `/labware-editor`, …) |
| Response | `image/png`, `image/jpeg` | Camera previews and rendered PDF pages |

## Errors

Four error shapes are produced, all JSON:

| Condition | Status | Body |
|---|---|---|
| `RuntimeError` (e.g. not connected, no address configured) | `400` | `{"error": "<message>"}` |
| `BravoError` (hardware/protocol failure) | `400` | `{"error": "<message>", "error_type": "<ErrorType name>"}` |
| `HTTPException` raised by a handler | as raised | `{"detail": <string or object>}` |
| Request body fails validation | `422` | `{"detail": [<pydantic errors>]}` |
| Any unhandled exception | `500` | `{"error": "Internal server error"}` |

Common `HTTPException` statuses in this codebase: `400` (bad argument), `404` (unknown id /
feature disabled), `409` (conflicting state — already connected, name already taken),
`500`/`501`/`502`/`503` (upstream service unavailable or not installed).

A few handlers return `{"status": "error", "message": …}` with HTTP `200` instead of raising —
notably `POST /api/execute_command` for an unrecognised command name.

---

## ⚠️ Endpoints that move physical hardware

This software drives a robot with a moving gantry, pipette head, and gripper. **Every endpoint in
the table below can cause physical motion.** Before calling any of them, confirm the deck is clear,
the enclosure is safe, and nobody's hands are inside the working envelope.

| Endpoint | What moves |
|---|---|
| `POST /api/initialize` | Full initialization sequence including homing |
| `POST /api/home` | All axes home, then travel to park positions |
| `POST /api/home_axis` | One axis homes |
| `POST /api/move` | One axis to an absolute position |
| `POST /api/jog` | One axis by a relative step |
| `POST /api/tip_force_jog` | Z axis under force control |
| `POST /api/move_to_location` | X/Y/Z travel to a taught deck location |
| `POST /api/move_safe_z` | Z retracts to the safe height |
| `POST /api/aspirate` | Travel + plunger motion |
| `POST /api/dispense` | Travel + plunger motion |
| `POST /api/tips_on` | Head presses into a tip box |
| `POST /api/tips_off` | Head ejects/returns tips |
| `POST /api/gripper/open` | Gripper jaws |
| `POST /api/gripper/close` | Gripper jaws |
| `POST /api/gripper/dock` | Gripper jaws + gripper Z |
| `POST /api/pick_place` | Full labware transfer between two locations |
| `POST /api/execute_command` | Dispatches to any of the above task APIs |
| `POST /api/workflows/{workflow_id}/execute` | Runs an entire workflow graph against live hardware |
| `POST /api/motor/enable`, `/disable`, `/enable_all`, `/disable_all` | No commanded motion, but disabling a servo can let a loaded axis drop under gravity |

**Destructive or disruptive endpoints** (no motion, but data loss or service interruption):
`POST /api/shutdown`, `DELETE /api/workflows/{id}`, `DELETE /labware/types/{id}`,
`DELETE /labware/classes/{id}`, `DELETE /liquid-classes/{id}`,
`DELETE /pipette-techniques/{id}`, `DELETE /tips/{id}`, `DELETE /api/deck/{location}/labware`,
`POST /api/profile/rename`, and `POST /api/profile/import_reg` /
`POST /api/profile/import_dat` when called with `overwrite: true`.

---

## Table of contents

- [Connection & Lifecycle](#connection--lifecycle)
- [Motion](#motion)
- [Teachpoints](#teachpoints)
- [Head & Tips](#head--tips)
- [State & Diagnostics](#state--diagnostics)
- [Vision](#vision)
- [Labware](#labware)
- [Liquid Classes & Pipette Techniques](#liquid-classes--pipette-techniques)
- [Deck](#deck)
- [Profiles](#profiles)
- [Device Discovery](#device-discovery)
- [Workflows](#workflows)
- [Protocol Assistant](#protocol-assistant)
- [Workflow Drafting (LLM)](#workflow-drafting-llm)
- [HTML pages and static mounts](#html-pages-and-static-mounts)
- [WebSocket: `/ws/state`](#websocket-wsstate)

---

## Conventions

**Axis names** (`X`, `Y`, `Z`, `W`, `G`, `Zg`) are matched case-insensitively. `W` is the plunger,
`G` the gripper jaws, `Zg` the gripper vertical axis. An unknown name returns `400`.

**Speed levels** are `FAST`, `MED`, `SLOW`, `HOMING`, `SAFE` (case-insensitive). Omitting `speed`
uses `MED`. An unknown value returns `400`.

**Deck locations** are integers `1`–`9`.

**Head types** are `HeadType` enum names, e.g. `HT_96_D_200`, `HT_96_D_70`, `HT_384_D_70`,
`HT_96_F_50`, `HT_96_ASSAYMAP`, `HT_96_PINTOOL`, `HT_384_PINTOOL`, `HT_1536_PINTOOL`,
`HT_UNKNOWN`.

**Controller types** referenced across the API: `simulation`, `agile`, `agile_7612`, `agile_srt`,
`darwin_native`, `darwin_serial`.

**"Requires a connection"** below means the endpoint calls into the controller and will fail with
`400 {"error": "Not connected"}` (or an equivalent `RuntimeError`) if no transport is open.

---

## Connection & Lifecycle

### POST `/api/connect`

Opens the configured controller transport and persists the resulting connection settings back into
the active profile. Any omitted field falls back to the value already stored in the profile. This
endpoint does **not** run initialization — call `POST /api/initialize` for that.

Request body — `ConnectRequest`:

| Field | Type | Notes |
|---|---|---|
| `controller_type` | `string \| null` | Falls back to the profile value |
| `address` | `string \| null` | IP address; required for `agile`, `agile_7612`, `agile_srt`, `darwin_native` |
| `serial_port` | `string \| null` | Required for `darwin_serial` |

Response: `{"status": "connected", "controller": "<controller_type>"}`

Errors: `400` when no address/serial port is configured for the selected controller type, or when
the socket cannot be opened.

### POST `/api/disconnect`

Closes the active controller connection.

Response: `{"status": "disconnected"}`

### POST `/api/shutdown`

**Destructive.** Best-effort disconnect, then hard-exits the server process shortly after the
response is flushed. Intended for a UI "Quit" button; it bypasses the graceful shutdown path.

Response: `{"status": "shutting_down"}`

### POST `/api/initialize`

⚠️ **Moves hardware.** Runs the device initialization sequence using the active profile, connecting
first if no session is open. Initialization homes axes and drives the robot to a known state.

Request body: none.

Response: `{"status": "initialized", "controller": "<controller_type>"}`

Errors: `400` when no address/serial port is configured, or the connection fails.

### POST `/api/home`

⚠️ **Moves hardware.** Retracts to safe Z, docks the gripper when one is present, homes the machine
axes, and moves the homed axes to their park positions. Requires a connection.

Response: `{"status": "homed", "axes": ["X", "Y", ...]}`

### POST `/api/abort`

Signals the task engine to abort the currently running operation.

Response: `{"status": "aborted", "accepted": <bool>}`

### POST `/api/retry`

Retries the current failed state-machine step.

Response: `{"status": "retried", "accepted": <bool>}`

### POST `/api/ignore`

Ignores the current task error and continues to the next step.

Response: `{"status": "ignored", "accepted": <bool>}`

---

## Motion

Every endpoint in this section requires an active hardware connection and moves the robot.

### POST `/api/move`

⚠️ **Moves hardware.** Absolute single-axis move in engineering units.

Request body — `MoveRequest`:

| Field | Type | Default |
|---|---|---|
| `axis` | `string` | required |
| `position` | `float` | required |
| `velocity` | `float` | `0.0` (controller default) |
| `acceleration` | `float` | `0.0` (controller default) |

Response: `{"status": "moved", "axis": "<axis>", "position": <float>}`

### POST `/api/jog`

⚠️ **Moves hardware.** Relative single-axis jog, used for manual positioning and teaching.

Request body — `JogRequest`:

| Field | Type | Default | Notes |
|---|---|---|---|
| `axis` | `string` | required | |
| `step` | `float` | required | Magnitude; sign is taken from `direction` |
| `direction` | `int` | `1` | `>= 0` positive, negative otherwise |
| `speed` | `string \| null` | `MED` | Speed level name |
| `peak_current` | `float \| null` | `null` | When set, performs a force-limited jog |

Response: `{"status": "jogged", "axis": "<axis>", "step": <signed float>, "position": <float>}`

### POST `/api/tip_force_jog`

⚠️ **Moves hardware.** Experimental force-controlled jog with position-based settle detection, used
for diagnosing tip-pickup behaviour. Reads the current position, computes `current + step` as the
travel limit, and drives the axis under a current cap.

Request body — `JogRequest` (same shape as `/api/jog`; `peak_current` defaults to `0.10` here).

Response:

```json
{"status": "jogged", "axis": "Z", "step": -2.0, "position": 12.3,
 "start": 14.3, "max_position": 12.3, "peak_current": 0.1}
```

Errors: `400` when the active controller does not implement `tip_force_jog`.

### POST `/api/home_axis`

⚠️ **Moves hardware.** Homes a single axis.

Request body — `AxisRequest`: `{"axis": "<axis>"}`

Response: `{"status": "homed", "axis": "<axis>"}`

### POST `/api/motor/enable`

Enables servo power for one axis. Request body — `AxisRequest`. Response:
`{"status": "enabled", "axis": "<axis>"}`

⚠️ Enabling or disabling a servo changes whether a loaded axis is held in place.

### POST `/api/motor/disable`

Disables servo power for one axis so it can be repositioned by hand. Request body — `AxisRequest`.
Response: `{"status": "disabled", "axis": "<axis>"}`

⚠️ A disabled vertical axis can drop under gravity.

### POST `/api/motor/enable_all`

Enables servo power on every axis. No request body. Response: `{"status": "all_enabled"}`

### POST `/api/motor/disable_all`

Disables servo power on every axis. No request body. Response: `{"status": "all_disabled"}`

⚠️ Disables the vertical axes as well — support the head before calling.

### POST `/api/move_to_location`

⚠️ **Moves hardware.** Sends the head to a taught deck location: retract Z to safe height, move X/Y
to the taught coordinates, then lower Z to the taught position or to an approach height above it.
The location must already have a valid teachpoint.

Request body — `MoveToLocationRequest`:

| Field | Type | Default |
|---|---|---|
| `location` | `int` | required |
| `approach_height` | `float` | `0.0` |
| `only_move_z` | `bool` | `false` |
| `speed` | `string \| null` | `MED` |

Response: `{"status": "moved", "location": <int>, "approach_height": <float>, "only_move_z": <bool>, "speed": "<SPEED>"}`

### POST `/api/move_safe_z`

⚠️ **Moves hardware.** Retracts the liquid-handling Z axis to the profile's configured safe
position. Z only.

Request body — `SpeedRequest`: `{"speed": "<string|null>"}`

Response: `{"status": "moved_safe_z", "speed": "<SPEED>"}`

### POST `/api/aspirate`

⚠️ **Moves hardware.** Runs an aspirate task at a taught location: retract, travel, lower to the
working depth, aspirate, retract. Tips and head configuration must already be correct.

**Query parameters** (not a JSON body):

| Parameter | Type |
|---|---|
| `location` | `int` |
| `volume` | `float` (µL) |

Response: `{"status": "completed"}`

For the full parameter set (pre/post-aspirate, distance from bottom, liquid class, technique) use
`POST /api/execute_command` with `command: "aspirate"`.

### POST `/api/dispense`

⚠️ **Moves hardware.** Runs a dispense task at a taught location.

**Query parameters:** `location` (`int`), `volume` (`float`, µL).

Response: `{"status": "completed"}`

### POST `/api/tips_on`

⚠️ **Moves hardware.** Picks up disposable tips from a tip-box location, using the active head mode
and tip-selection anchor to decide which tips are acquired.

**Query parameter:** `location` (`int`).

Response: `{"status": "completed"}`

### POST `/api/tips_off`

⚠️ **Moves hardware.** Returns or discards the tips currently on the head at the given location.

**Query parameter:** `location` (`int`).

Response: `{"status": "completed"}`

### POST `/api/gripper/open`

⚠️ **Moves hardware.** Opens the gripper. No request body.

Response: `{"status": "opened"}`

### POST `/api/gripper/close`

⚠️ **Moves hardware.** Closes the gripper. No request body.

Response: `{"status": "closed"}`

### POST `/api/gripper/dock`

⚠️ **Moves hardware.** Opens the gripper and drives it into its docked/recessed position. No request
body.

Response: `{"status": "docked", "g_target": <float>, "zg_target": <float>, "forced_plate_sensor": <bool>}`
— or `{"status": "aborted", "message": "…"}` when the operator aborts the task.

### POST `/api/pick_place`

⚠️ **Moves hardware.** Full gripper-based labware transfer: retract, open and nest the gripper,
travel to the source, grip, lift to a carry height, travel to the destination, release, and
re-nest. Intermediate poses are solved from teachpoints plus labware handling geometry.

Request body — `PickPlaceRequest`:

| Field | Type | Default |
|---|---|---|
| `from_location` | `int` | required |
| `to_location` | `int` | required |
| `speed` | `string \| null` | `MED` |

Response: `{"status": "completed", "from": <int>, "to": <int>, "diagnostics": {...}}` — `diagnostics`
carries the solved pick, carry, and place positions.

### POST `/api/execute_command`

⚠️ **Moves hardware.** Generic dispatcher: runs one named high-level task through a single request
shape. `command` is lower-cased and spaces become underscores.

Supported `command` values: `aspirate`, `dispense`, `mix`, `tips_on`, `tips_off`, `stack_plates`,
`destack_plate`, `mount_plates`, `unmount_plate`, `delid_plate`, `relid_plate`,
`scan_stack_height`, `read_barcode`.

Request body — `ExecuteCommandRequest`:

| Field | Type | Default | Used by |
|---|---|---|---|
| `command` | `string` | required | all |
| `location` | `int` | `1` | aspirate, dispense, mix, tips_on, tips_off, scan_stack_height, read_barcode |
| `source_location` | `int \| null` | `null` | stack_plates, destack_plate, mount_plates, unmount_plate |
| `base_location` | `int \| null` | `null` | stack_plates, mount_plates |
| `destination_location` | `int \| null` | `null` | destack_plate, unmount_plate |
| `lid_location` | `int \| null` | `null` | relid_plate |
| `plate_location` | `int \| null` | `null` | delid_plate, relid_plate |
| `lid_destination` | `int \| null` | `null` | delid_plate |
| `manual_count` | `int \| null` | `null` | scan_stack_height |
| `volume` | `float` | `0.0` | aspirate, dispense, mix |
| `pre_aspirate` | `float` | `0.0` | aspirate, mix |
| `post_aspirate` | `float` | `0.0` | aspirate |
| `distance_from_bottom` | `float` | `2.0` | aspirate, dispense, mix |
| `aspirate_distance` | `float \| null` | `null` | mix (falls back to `distance_from_bottom`) |
| `dispense_distance` | `float \| null` | `null` | mix (falls back to `distance_from_bottom`) |
| `dispense_at_different_distance` | `bool` | `false` | mix |
| `blowout` | `float` | `0.0` | dispense, mix |
| `empty_tips` | `bool` | `false` | dispense |
| `mix_cycles` | `int` | `3` | mix |
| `dynamic_tip_extension` | `float` | `0.0` | aspirate, mix |
| `dynamic_tip_retraction` | `float` | `0.0` | dispense |
| `tip_touch` | `bool` | `false` | aspirate, dispense, mix |
| `liquid_class` | `string \| null` | `null` | aspirate, dispense, mix |
| `pipette_technique` | `string \| null` | `null` | aspirate, dispense, mix |

Responses:

- `aspirate`, `dispense`, `mix`, `tips_on`, `tips_off` → `{"status": "completed", "command": "<command>"}`
- `stack_plates`, `destack_plate`, `mount_plates`, `unmount_plate`, `delid_plate`, `relid_plate`,
  `scan_stack_height`, `read_barcode` → the task's own result object is returned verbatim; see the
  corresponding `Bravo` method for the exact fields.
- Unknown command → HTTP `200` with `{"status": "error", "message": "Unknown command: <name>"}`

---

## Teachpoints

Teachpoints hold the reference X/Y/Z coordinates for each deck location and are the basis for every
location-driven task.

### GET `/api/teachpoint/{location}`

Reads the taught coordinates for one deck location.

| Path parameter | Type |
|---|---|
| `location` | `int` |

Response: `{"location": <int>, "teachpoint": {"x": <float>, "y": <float>, "z": <float>}}`, or
`{"location": <int>, "teachpoint": null}` when the location has never been taught.

### POST `/api/teachpoint/{location}`

Writes explicit X/Y/Z coordinates into the teachpoint store.

Path parameter: `location` (`int`). Request body — `TeachpointSetRequest`:
`{"x": <float>, "y": <float>, "z": <float>}`

Response: `{"status": "taught", "location": <int>}`

### POST `/api/teachpoint/{location}/teach_current`

Captures the robot's **current** X/Y/Z position as the teachpoint for a location. Requires a
connection (it reads live axis positions) and writes the resolved teach-tip fields back into the
active profile, saving it to disk.

Path parameter: `location` (`int`). Request body — `TeachCurrentRequest` (optional):

| Field | Type | Notes |
|---|---|---|
| `tip_capacity` | `float \| null` | Resolves a tip definition by capacity |
| `tip_id` | `string \| null` | Takes precedence over `tip_capacity` |

If neither is supplied, the profile's `teach_tip_capacity` / `default_tip_capacity` is used.

Response:

```json
{
  "status": "taught",
  "location": 4,
  "teach_tip_id": "...",
  "teach_tip_capacity": 200.0,
  "teach_tip_height_mm": 51.0,
  "teach_tip": {"tip_id": "...", "capacity_ul": 200.0, "label": "...",
                "length_mm": 51.0, "source": "...", "model_3d": "..."},
  "teachpoint": {"x": 0.0, "y": 0.0, "z": 0.0}
}
```

---

## Head & Tips

### GET `/api/head_mode`

Returns the active head-mode configuration — which subset of the head's barrels is considered
active for tip and liquid-handling operations.

Response: `{"head_type": "<HeadType name>", "head_mode": {...}}`

The `head_mode` object contains `subset_type`, `subset_config`, `row_count`, `column_count`,
`num_channels`, and `display_text`.

### PUT `/api/head_mode`

Updates the active head-mode configuration. Values are normalised against the installed head's
geometry, so out-of-range or unsupported combinations fall back to sane defaults rather than
erroring.

Request body — `HeadModeRequest`:

| Field | Type | Accepted values |
|---|---|---|
| `subset_type` | `string \| null` | `all_barrels`, `row`, `column`, `rectangle`, `single_barrel`, `quadrant` (normalised to `rectangle`) |
| `subset_config` | `string \| null` | `front_left`, `front_right`, `back_left`, `back_right` |
| `row_count` | `int \| null` | Used by `row` and `rectangle` |
| `column_count` | `int \| null` | Used by `column` and `rectangle` |

Response: `{"status": "updated", "head_type": "<HeadType name>", "head_mode": {...}}`

### GET `/api/head_mode/suggest`

Suggests a head mode for the labware currently assigned to a deck location, based on the installed
head and the labware's well count.

| Query parameter | Type |
|---|---|
| `location` | `int` |

Response: `{"location": <int>, "wells": <int|null>, "head_type": "<name>", "head_mode": {...}}`

### GET `/api/tipbox/legal_anchors`

Computes the anchor positions at which the given head mode can legally engage a tip box of the
given dimensions — i.e. placements where inactive barrels will not collide with tips. Used by the
designer's Tips On / Tips Off pickers.

| Query parameter | Type | Default | Notes |
|---|---|---|---|
| `subset_type` | `string` | `all_barrels` | |
| `subset_config` | `string` | `back_left` | |
| `row_count` | `int \| null` | `null` | |
| `column_count` | `int \| null` | `null` | |
| `tipbox_rows` | `int` | `8` | Must be positive |
| `tipbox_cols` | `int` | `12` | Must be positive |
| `purpose` | `string` | `pickup` | `pickup` or `return` |
| `occupied_cells` | `string \| null` | `null` | Comma-separated `row:col` pairs, e.g. `0:0,0:1,1:2` |

When `occupied_cells` is omitted, occupancy is inferred from `purpose`: `pickup` assumes a full box,
`return` assumes an empty one. Malformed tokens in `occupied_cells` are silently dropped.

Response:

```json
{"head_mode": {...}, "tipbox_rows": 8, "tipbox_cols": 12, "purpose": "pickup",
 "occupied_cells_count": 96, "legal_anchors": [{"row": 0, "col": 0, ...}, ...]}
```

Errors: `400` for an invalid head mode, non-positive box dimensions, or an unknown `purpose`.

### GET `/api/tip_selection`

Returns the current tip-selection anchor and the selection recorded for the tips presently on the
head.

Response: `{"tip_selection": {...} | null, "tips_on_head_selection": {...} | null}`

Each selection object carries `location`, `row`, `col`, `row_count`, `column_count`,
`mirror_corner`, `head_anchor`, `anchor_row`, `anchor_col`.

### PUT `/api/tip_selection`

Sets the anchor well used for partial tip pickup and return. The selection is validated against the
head mode, tip-box geometry, and accessibility rules.

Request body — `TipSelectionRequest`: `{"location": <int>, "row": <int>, "col": <int>}`

Response: `{"status": "updated", "tip_selection": {...}}`

### GET `/api/plate_selection`

Returns the current plate anchor for a location, the legal anchors, and the well footprint the head
would cover.

| Query parameter | Type |
|---|---|
| `location` | `int` |

Response: `{"location": <int>, "selection": {...} | null, "legal_anchors": [...], "footprint": [{"row": <int>, "col": <int>}, ...], "rows": <int>, "cols": <int>}`

### PUT `/api/plate_selection`

Sets the selected plate anchor well for a location.

Request body — `PlateSelectionRequest`: `{"location": <int>, "row": <int>, "col": <int>}`

Response: `{"status": "updated", "plate_selection": {...}, "legal_anchors": [...], "footprint": [...]}`

### GET `/api/tips`

Lists tip definitions.

| Query parameter | Type | Notes |
|---|---|---|
| `head_type` | `string \| null` | When set, returns only tips compatible with that head, in the head's option format |

Response: `{"tips": [...]}`

### POST `/tips`

Creates a tip definition.

Request body — `TipDefinitionRequest` (all fields optional; `None` values are dropped before the
store sees them):

| Field | Type |
|---|---|
| `tip_id` | `string` |
| `label` | `string` |
| `capacity_ul` | `float` |
| `length_mm` | `float` |
| `source` | `string` |
| `model_3d` | `string` |
| `compatible_heads` | `string[]` |

Response: `{"tip": {...}}`. Errors: `400` on invalid input.

### PATCH `/tips/{tip_id}`

Updates a tip definition. Path parameter `tip_id` (`string`); body — `TipDefinitionRequest`.

Response: `{"tip": {...}}`. Errors: `404` unknown tip, `400` invalid input.

### DELETE `/tips/{tip_id}`

**Destructive.** Deletes a tip definition.

Response: `{"status": "deleted", "tip_id": "<id>"}`. Errors: `404` unknown tip.

### POST `/api/change_head`

Changes the configured head type and resets the active head mode to the default full-head
configuration (`all_barrels` / `back_left`). If the controller supports it, the new head type is
pushed down to the controller as well.

Request body — `ChangeHeadRequest`: `{"head_type": "<HeadType name>"}`

Response: `{"status": "head_changed", "head_type": "<name>", "head_type_display": "<label>"}`

Errors: `400` for an unknown head type name.

---

## State & Diagnostics

### GET `/api/state`

Returns the consolidated runtime state used by the UI. This is the same payload broadcast over
`/ws/state`. Position and I/O fields are populated only while connected; during active motion the
server serves a cached snapshot rather than issuing live reads.

Key fields:

| Field | Type | Description |
|---|---|---|
| `connected` | `bool` | Transport is open |
| `initialized` | `bool` | Initialization has completed |
| `positions` | `{axis: float}` | Current engineering-unit positions |
| `head_type` | `string` | Installed head type name |
| `machine_id` | `string` | Machine identifier from the profile |
| `active_tip_id` | `string` | Resolved active tip definition |
| `active_tip_capacity_ul` | `float` | Capacity of the active tip |
| `head_mode` | `object` | Active head-mode configuration |
| `tips_on_head_mode` | `object \| null` | Head mode captured when tips were picked up |
| `tip_selection` | `object \| null` | Current tip anchor |
| `tips_on_head_selection` | `object \| null` | Anchor of the tips currently mounted |
| `plate_selection` | `{location: object}` | Per-location plate anchors |
| `controller_type` | `string` | Active controller type |
| `deck` | `{location: string[]}` | Labware names stacked at each location |
| `deck_details` | `{location: object[]}` | Full labware metadata plus `is_mounted` |
| `engine_busy` | `bool` | Task engine is running something |
| `motors_enabled` | `{axis: bool}` | Servo enable state per axis |
| `telemetry` | `object` | Controller-supplied telemetry |
| `head_attached` | `bool` | Head presence |
| `go_button_pressed` | `bool` | Front-panel button state |
| `plate_in_gripper` | `bool` | Resolved plate presence |
| `tips_on_head` | `bool` | Tips currently mounted |
| `tip_labware` | `string \| null` | Name of the tip-box labware in use |
| `tip_definition_id` | `string \| null` | Tip definition of the mounted tips |
| `attached_tip_length_mm` | `float \| null` | Length of the mounted tips |
| `tipbox_inventory` | `object` | Per-location tip occupancy |
| `robot_disabled` | `bool` | Safety/disable flag |
| `teachpoints` | `{location: {x, y, z}}` | Taught positions for locations 1–9 |
| `task_status` | `object` | Active task: `step`, `step_index`, `step_count`, `status`, optional `error` |

### GET `/api/positions`

Returns just the current axis positions.

Response: `{"X": <float>, "Y": <float>, "Z": <float>, "W": <float>, "G": <float>, "Zg": <float>}` —
axes that cannot be read are omitted.

### GET `/api/io_status`

Compact safety/I-O view derived from the full state.

Response: `{"robot_disabled": <bool>, "head_attached": <bool>, "head_type": "<string>", "go_button_pressed": <bool>, "plate_in_gripper": <bool>, "motors_enabled": {axis: bool}}`

### GET `/api/diagnostics`

Returns wire-level protocol diagnostics — command counts and the error log from the comm layer.
Only available on controllers that implement a diagnostics hook (currently `agile_7612`).

Response: the controller's diagnostics object, or
`{"error": "Diagnostics not available for this controller type"}` with HTTP `200` on other
controllers.

### GET `/api/accessories`

Lists configured accessories with their lazy-loaded driver runtime state.

Response: `{"devices": [{<device config fields>, "runtime": {"loaded": <bool>, "is_open": <bool>, "is_running": <bool>}}, ...]}`

### POST `/api/accessories/{accessory_id}/teleshake/start`

Starts a configured orbital shaker accessory. **Physically actuates the accessory** — make sure any
labware on the shaker is seated.

Path parameter: `accessory_id` (`string`). Request body — `TeleshakeActionRequest`:

| Field | Type | Notes |
|---|---|---|
| `rpm` | `int \| null` | Shake speed; driver default when omitted |
| `direction` | `string \| null` | Rotation direction; driver default when omitted |

Response: the driver's result object; see the handler. Errors: `400` when the accessory id is not
configured, `500` on driver failure.

### POST `/api/accessories/{accessory_id}/teleshake/stop`

Stops the shaker. Path parameter `accessory_id` (`string`); no body.

Response: the driver's result object. Errors: `400` unknown accessory, `500` driver failure.

---

## Vision

These endpoints proxy to a local vision service process (depth camera integration). **All of them
return `404` when `vision.enabled` is false in the active profile**, and `503` when the local
service is unreachable.

### GET `/api/vision/status`

Reports vision-service connectivity, camera SDK availability, and the saved calibration artifact.

Response: the service's `/status` payload.

### GET `/api/vision/calibration`

Returns the saved camera-to-deck calibration for the active machine.

Response: the service's `/calibration` payload.

### POST `/api/vision/calibration/run`

Starts the guided calibration workflow, or creates a calibration scaffold when hardware is not
ready. The active machine id is sent along automatically.

Request body — `VisionCalibrationRunRequest`: `{"notes": "<string|null>"}`

Response: the service's `/calibration/run` payload.

### POST `/api/vision/calibration/capture_baselines`

Captures a live depth reference for all 9 calibrated deck ROIs. Run with an **empty deck**, after
ROI calibration and before verification. No request body.

Response: the service's `/calibration/capture_baselines` payload.

### POST `/api/vision/verify`

Builds the expected deck scene from current deck assignments, teachpoints, head type, and tip-box
occupancy, sends it to the vision service, and returns a slot-by-slot comparison against what the
camera observes. No request body.

Response: the service's `/verify` payload — a report with per-slot expected labware, observed
status, and confidence.

### GET `/api/vision/preview`

Returns the latest camera preview image. Response body is raw bytes with the content type reported
by the vision service (typically `image/jpeg` or `image/png`).

### GET `/api/vision/preview/depth`

Returns the latest colorized depth preview image. Same response handling as `/api/vision/preview`.

### GET `/api/vision/detect`

*Excluded from the OpenAPI schema.* Fetches the service's live detection report and decorates each
slot with the labware pyBravo expects there, adding `expected_labware` and a `display_label` to
every slot entry.

Response: the service's `/detect` payload with the added per-slot fields.

### GET `/api/vision/stream`

*Excluded from the OpenAPI schema.* Issues a `307` redirect to the vision service's MJPEG stream
URL.

### GET `/api/vision/stream/depth`

*Excluded from the OpenAPI schema.* `307` redirect to the depth stream URL.
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

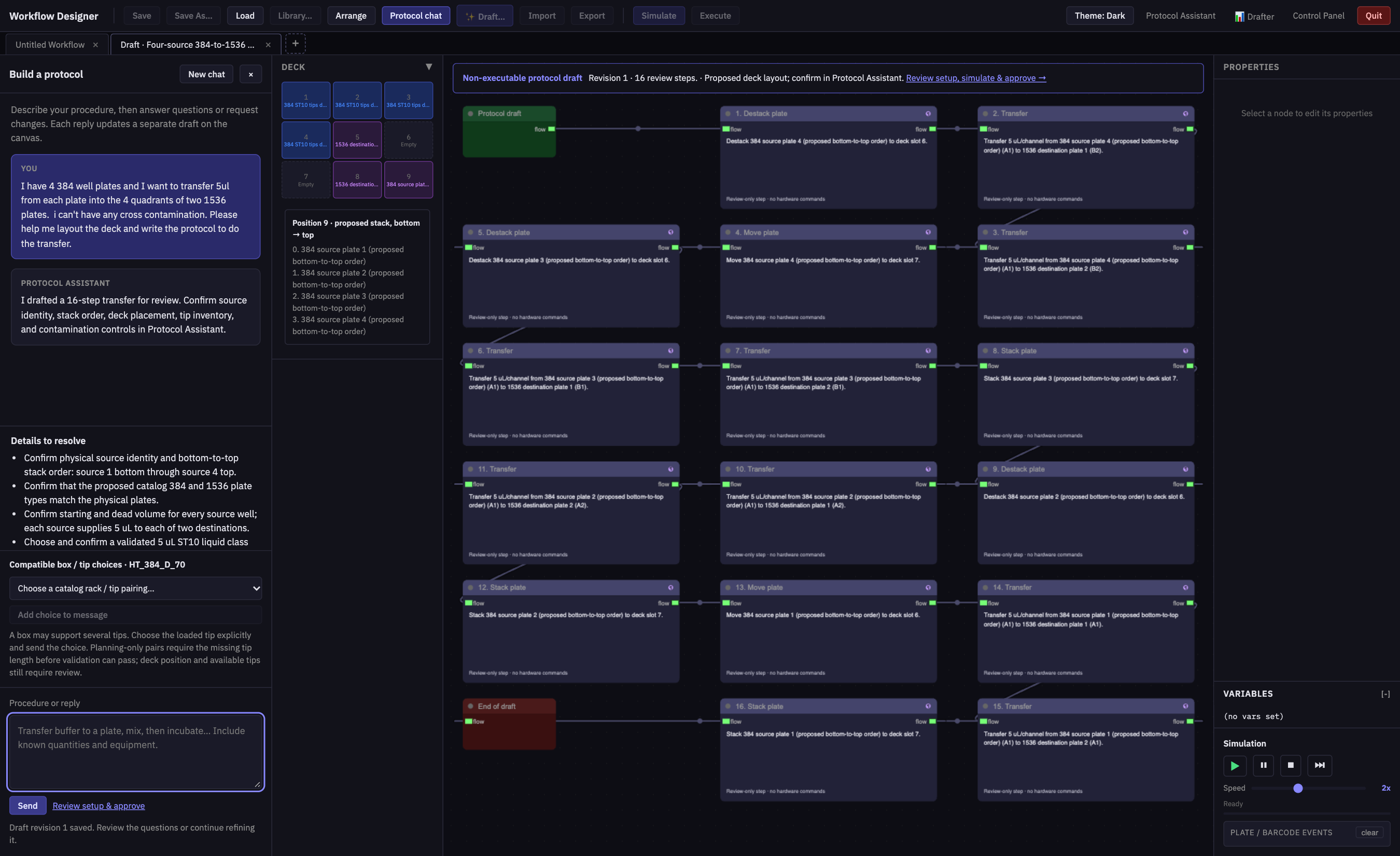
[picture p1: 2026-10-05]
docs/media/1536-transfer-draft-designer.png

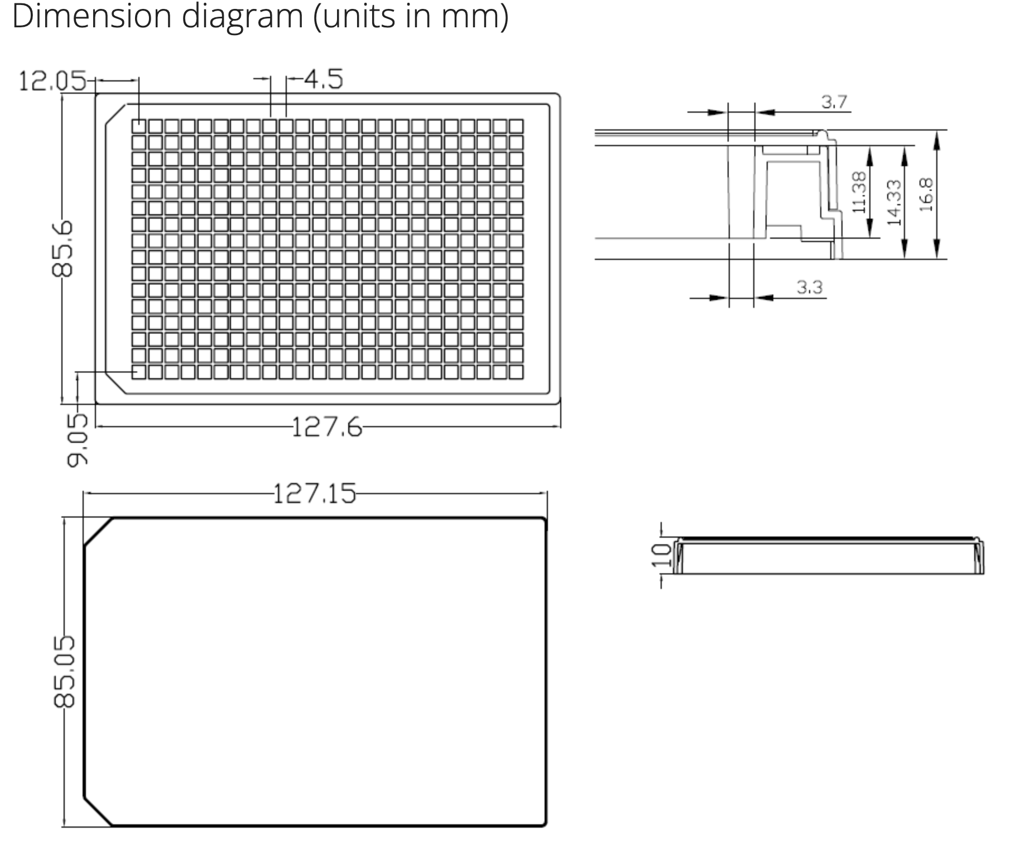
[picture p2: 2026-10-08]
docs/media/cellvis-384-plate-lid-dimensions.png

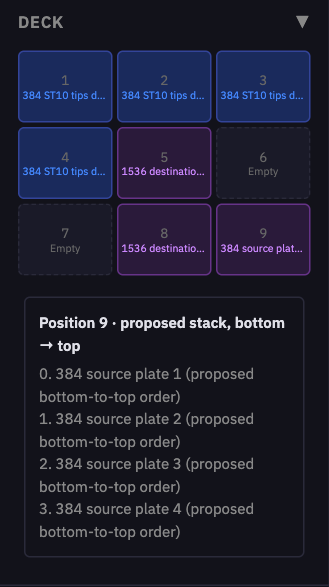
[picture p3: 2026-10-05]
docs/media/1536-transfer-deck-layout.png

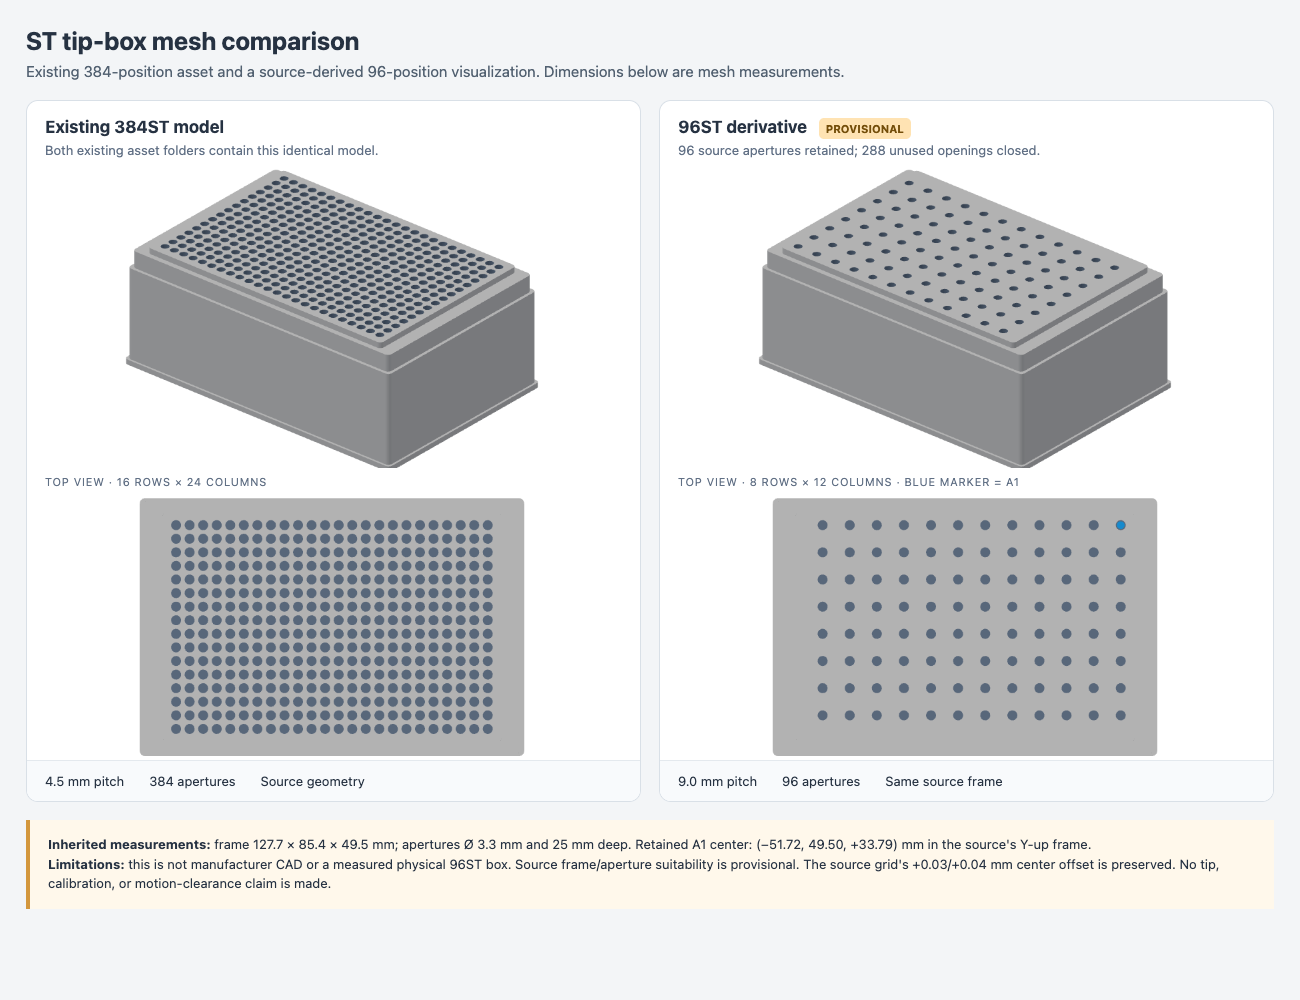
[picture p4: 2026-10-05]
docs/media/96st-provisional-comparison.png

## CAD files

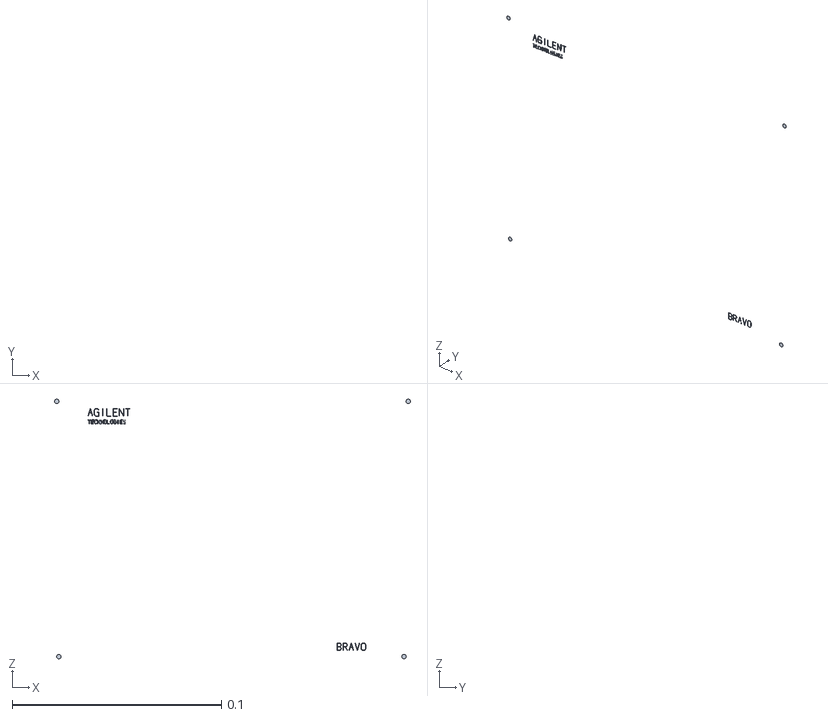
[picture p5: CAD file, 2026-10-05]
pybravo/model/pybravo_urdf/assets/bravo_cover_markings.stl
0.17 x 0 x 0.124

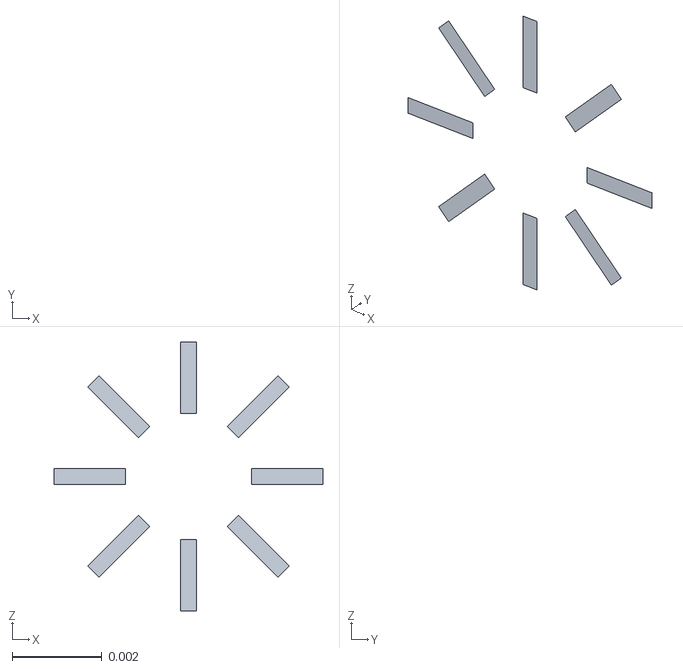
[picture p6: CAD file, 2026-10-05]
pybravo/model/pybravo_urdf/assets/bravo_brand_emblem.stl
0.006 x 0 x 0.006

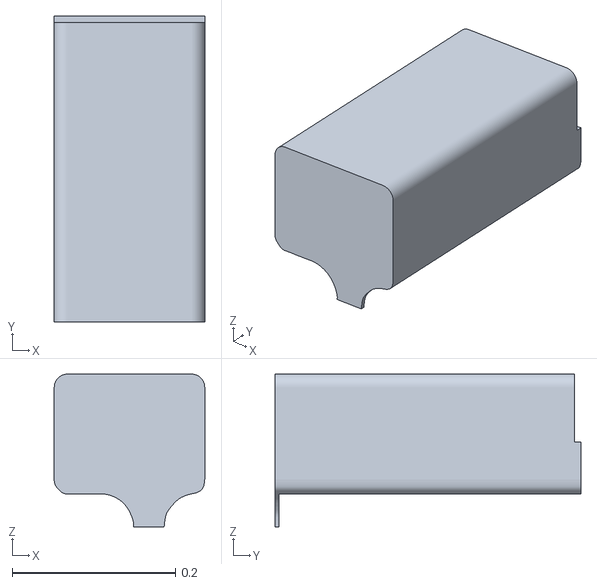
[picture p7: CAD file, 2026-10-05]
pybravo/model/pybravo_urdf/assets/bravo_gantry_cover.stl
0.184 x 0.375 x 0.187

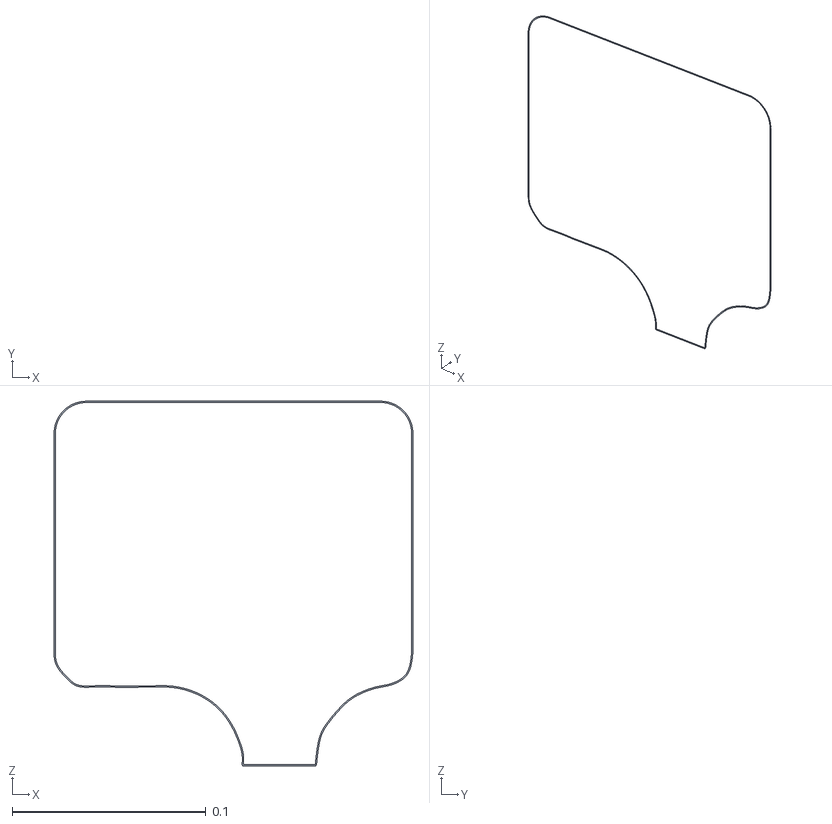
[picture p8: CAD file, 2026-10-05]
pybravo/model/pybravo_urdf/assets/bravo_cover_trim.stl
0.185 x 0 x 0.188

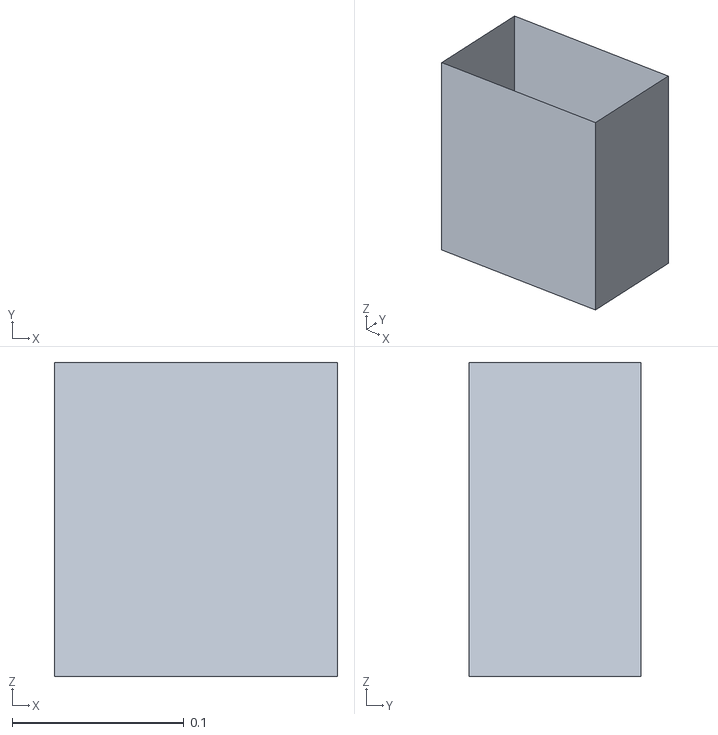
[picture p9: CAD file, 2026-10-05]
pybravo/model/pybravo_urdf/assets/bravo_head_lower.stl
0.165 x 0.1 x 0.183

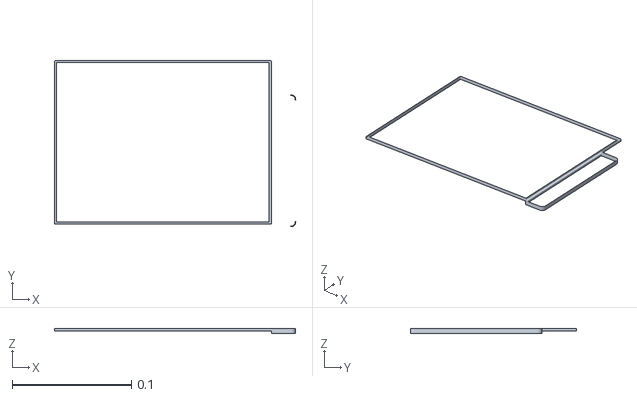
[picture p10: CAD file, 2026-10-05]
pybravo/model/pybravo_urdf/assets/bravo_carriage_seam.stl
0.202 x 0.139 x 0.004

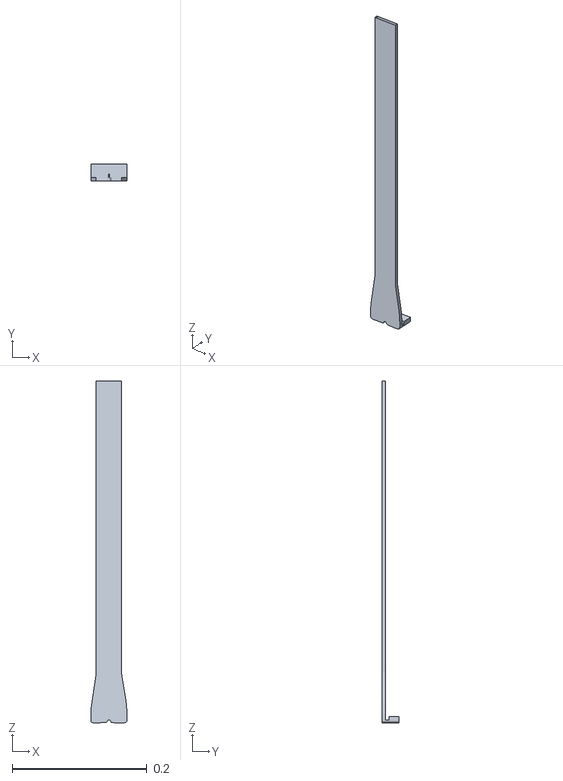
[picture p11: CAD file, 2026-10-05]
pybravo/model/pybravo_urdf/assets/bravo_front_support.stl
0.0541 x 0.0254 x 0.508

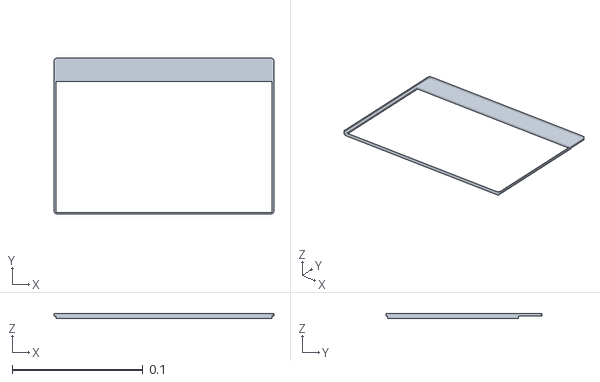
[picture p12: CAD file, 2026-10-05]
pybravo/model/pybravo_urdf/assets/bravo_head_gasket.stl
0.168 x 0.119 x 0.004

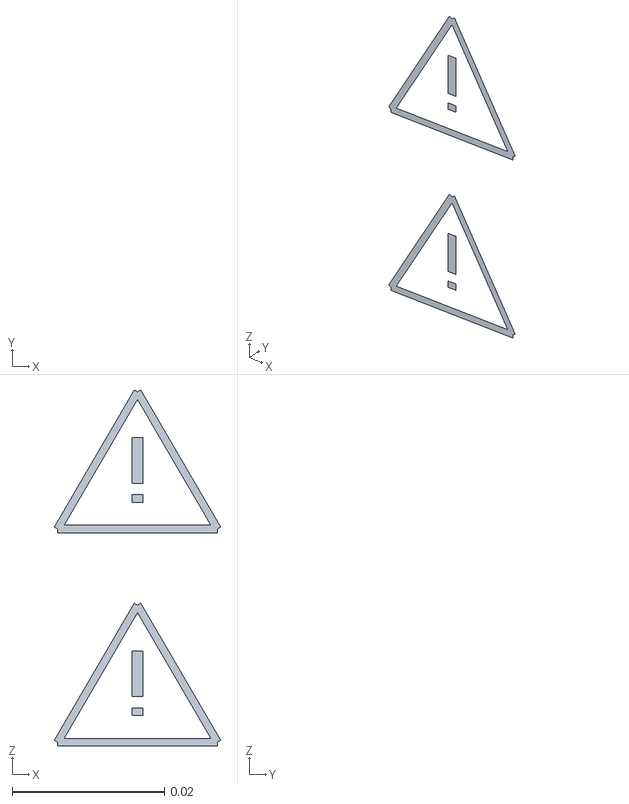
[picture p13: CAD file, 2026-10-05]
pybravo/model/pybravo_urdf/assets/bravo_warning_ink.stl
0.0219 x 0 x 0.0468

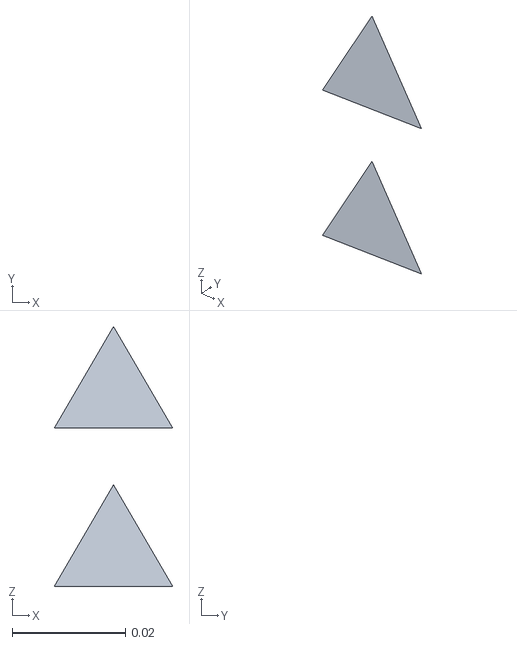
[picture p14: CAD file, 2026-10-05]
pybravo/model/pybravo_urdf/assets/bravo_warning_yellow.stl
0.021 x 0 x 0.046

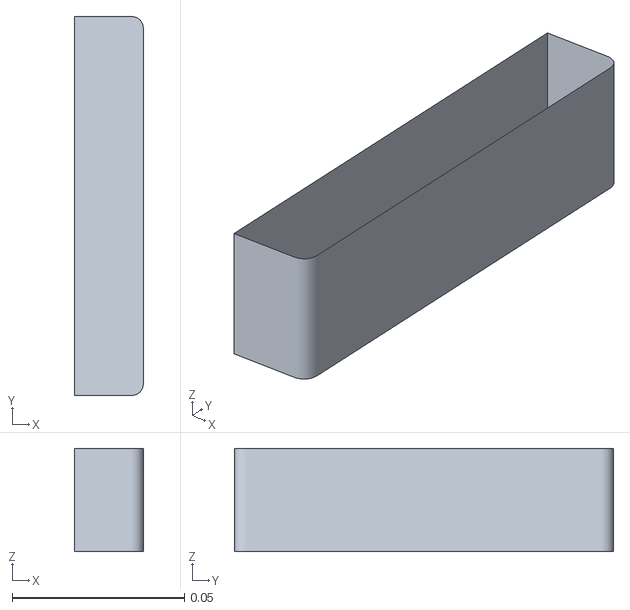
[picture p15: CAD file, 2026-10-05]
pybravo/model/pybravo_urdf/assets/bravo_carriage_trim.stl
0.02 x 0.11 x 0.03

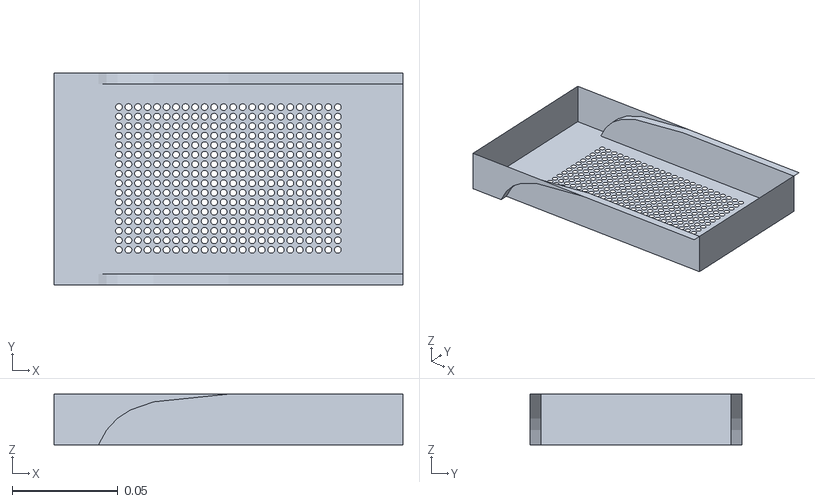
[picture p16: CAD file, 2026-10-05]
pybravo/model/pybravo_urdf/assets/bravo_head_tooling.stl
0.165 x 0.1 x 0.024

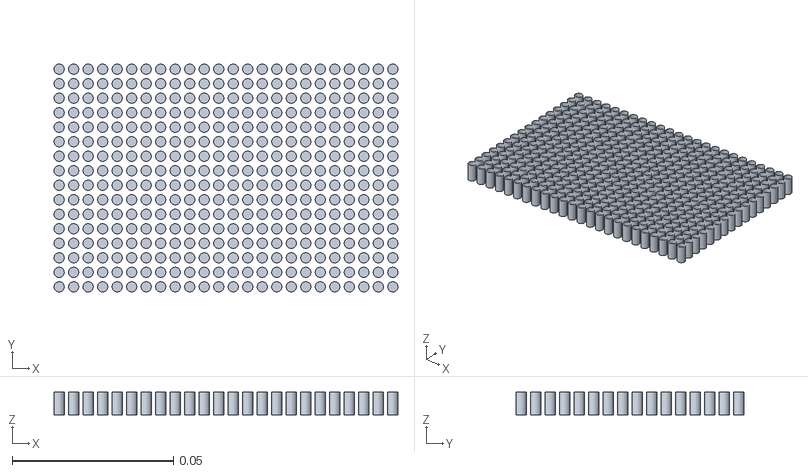
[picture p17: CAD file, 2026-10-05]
pybravo/model/pybravo_urdf/assets/bravo_head_barrels.stl
0.107 x 0.0707 x 0.007

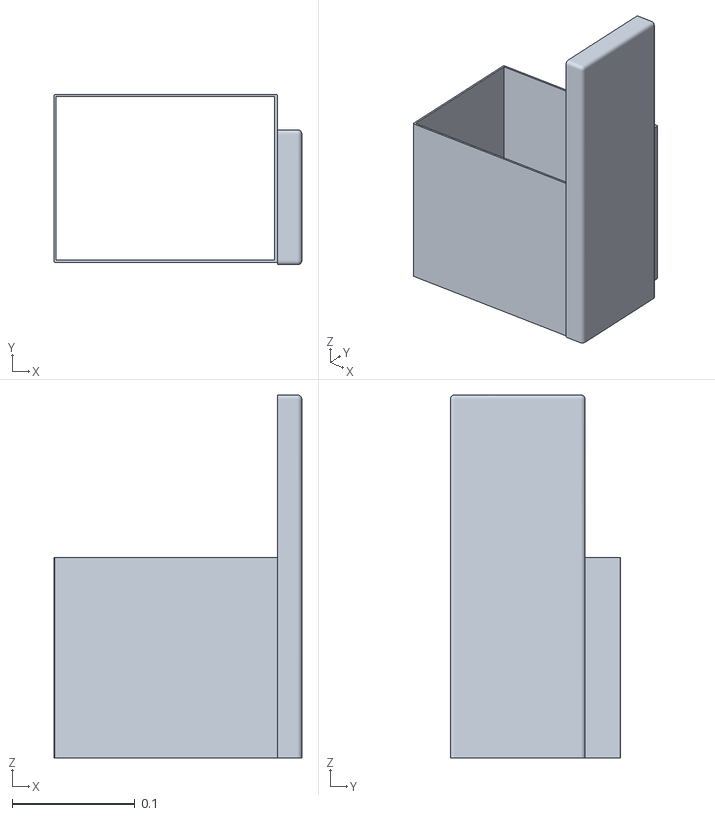
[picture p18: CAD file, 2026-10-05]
pybravo/model/pybravo_urdf/assets/bravo_carriage_cover.stl
0.202 x 0.139 x 0.296

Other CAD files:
pybravo/model/pybravo_urdf/assets/bravo_head_upper.stl

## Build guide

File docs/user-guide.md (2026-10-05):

# User guide

A tour of the pyBravo web interface: the operator dashboard, the editors for
labware, tips and liquid classes, and the normal order of operations for
bringing an instrument from cold to working.

This guide assumes the server is already running and reachable. If it is not,
start with [installation](installation.md) and [quickstart](quickstart.md).

> **This software moves a physical robot.** Most of the controls described
> below command motion the moment they are clicked — there is no separate
> confirmation step. Read [safety](safety.md) before you operate real hardware,
> and keep hands clear of the deck whenever the instrument is connected.

---

## The pages

The server publishes several browser pages from one process:

| Path | Page | Purpose |
|---|---|---|
| `/` | Control panel | Day-to-day operation: connect, home, jog, pipette, move plates |
| `/designer` | Workflow designer | Build, simulate and run node-graph protocols |
| `/protocol-assistant` | Protocol Assistant | Interpret text/PDF protocols with a local model, review and release workflows |
| `/labware-editor` | Labware dashboard | Edit labware entries and labware classes |
| `/liquid-class-editor` | Liquid class editor | Edit liquid classes and pipette techniques |
| `/tip-editor` | Tip editor | Edit tip definitions |
| `/vision-calibration` | Vision calibration | Calibrate and verify the optional deck camera |
| `/workflow` | Workflow editor (earlier) | Superseded by `/designer` |

`/workflow` is an earlier, simpler workflow editor that is still served for
backwards compatibility. `/designer` is the actively developed one; use it for
anything new. Everything about it is covered in [workflows](workflows.md).

---

## Order of operations

The instrument has to be brought up in a fixed order. Each step depends on the
one before it.

1. **Pick a profile.** The *Profiles* tab selects which YAML profile is active.
   The profile carries the controller type, network address, head type,
   teachpoints and safety preferences. See [configuration](configuration.md).
2. **Connect.** The `Connect` button in the header opens the transport to the
   instrument. That is all it does — it does **not** initialize the instrument,
   and the robot is not ready for motion until you initialize it separately.
3. **Initialize.** Initialization verifies communication and runs the standard
   startup task sequence for the configured controller. **This causes motion.**
4. **Home.** `Home All` retracts to a safe Z, places the gripper in a safe
   docked state where one is fitted, homes the machine axes, and moves the
   homed axes to their park positions. **This causes motion.** Individual axes
   can be homed from the per-axis `Home` buttons on the *Jog/Teach* and
   *Gripper* tabs.
5. **Describe the deck.** Assign labware to each occupied deck location on the
   *Config* tab. Motion planning, collision checks and the 3D view all depend
   on the software knowing what is physically present.
6. **Work.** Jog, teach, pipette, or run a workflow.

`Abort` in the header signals the task engine to stop the operation currently
running. It is the control to reach for when something looks wrong; for a true
emergency, use the instrument's own emergency stop. `Quit` terminates the
backend server process.

The connection indicator beside the title shows the live transport state, and
the log panel along the bottom of the page records every command and its
result.

---

## The 3D viewport

The left side of the control panel renders a URDF model of the robot — the
digital twin. It mirrors the axis positions streamed from the instrument, and
draws the labware currently assigned to each deck location, tips on the head,
and plates held in the gripper. In simulation mode it is driven by the
simulated controller instead, which is what makes it useful for rehearsing a
layout before any hardware is involved.

The viewport is a display, not a control surface: nothing you do in it moves
the robot.

---

## Control panel tabs

### Jog / Teach

**Axis positions** shows the four machine axes with their live values and a
per-axis `Home` button:

| Axis | Direction | Unit |
|---|---|---|
| X | left / right | mm |
| Y | back / front | mm |
| Z | up / down | mm |
| W | aspirate / dispense (plunger) | µL |

**Jog axes** is a directional pad: `Left −X` / `Right +X`, `Back −Y` /
`Fwd +Y`, `Up −Z` / `Down +Z`, and `Asp +W` / `Dsp −W`. Each group has its own
step-size selector — W in µL, XY in mm, Z in mm — plus a `Speed` selector with
Slow, Medium and Fast. **Every jog button commands immediate motion.** Start
with a small step size, especially near labware.

A `Diagnostics` checkbox reveals a `Z current limit` selector. With it enabled,
Z jogs run in force-limited mode and stop when the selected current is reached.

**Teachpoints** define the reference X, Y and Z coordinates for each of the
nine deck locations. Pick a `Location`, then:

- `Move` drives to the stored teachpoint. **Causes motion.**
- `Approach` drives to the stored teachpoint offset upward by the
  `Approach height` value. **Causes motion.**
- `Teach` writes the robot's current position into that location's teachpoint.
- `Move to Safe Z` retracts Z to the profile's configured safe position.
  **Causes motion.**

The `Tip` selector tells the teaching maths which tip is fitted, since tip
length changes where the head has to sit to reach a given well. Teaching
procedure and tolerances are covered in [hardware setup](hardware-setup.md).

**Multiple axes** offers `Home XYZ` (**causes motion**), `Enable All Motors`
and `Disable All Motors`. Disabling motors removes servo power so axes can be
repositioned by hand — which also means an unsupported axis can fall under its
own weight. Read [safety](safety.md) before disabling motors.

### Gripper

**Gripper axes** shows the two gripper axes with live values and `Home`
buttons: `G` (open/close, mm) and `Zg` (up/down, mm).

**Jog gripper axes** provides `Up −Zg` / `Down +Zg` and `Open −G` / `Close +G`
with their own step selectors. **Causes motion.**

**Gripper actions** are `Open Gripper`, `Close Gripper` and `Dock Gripper`
(opens and stows the gripper). A status lamp reports whether a plate is
detected in the gripper. **All three cause motion.**

**Pick and place** moves labware between two deck locations. Choose
`Location A` and `Location B`, then run `Pick A → Place B` or
`Pick B → Place A`. **These run a full transport sequence** — the gripper
descends, grips, lifts, traverses and sets down. Confirm both locations hold
what you think they hold before running it.

**Gripper teaching** calibrates the gripper against a specific labware type:
choose the `Labware`, set the `Y offset` and `Approach` height, then use
`Teach Y Offset`, `Approach` and `Move`. The latter two **cause motion**.

### Config

**Location configuration** is where the software is told what is on the deck.
Select a `Location` (1–9), a location `Type` (standard platepad or accessory),
and a `Labware` definition, tick `Lidded` and/or `Sealed` as appropriate, then
`Assign Labware`. `Clear Location` removes the assignment.

Accurate deck assignment is not cosmetic. Motion planning, the collision check
that blocks unsafe head moves, tip-box inventory tracking and the 3D view all
read from it. A location that is physically occupied but empty in software is
a collision waiting to happen.

**Deck layout** shows the 3×3 grid with the labware currently assigned to each
position.

**Deck verification** appears when the optional camera is enabled in the
profile. `Verify Deck Setup` compares what the camera sees against what the
software believes is on the deck; `Vision Calibration` opens the calibration
page.

**Accessories** manages hardware attached to a deck location — a barcode
reader or an orbital shaker. Each accessory has a name, ID, type, deck
location, serial port, and a flag for whether it can hold labware. Barcode
readers add a scanner model and a side (east or west); shakers add a default
RPM, a shake direction, an optional temperature-control flag, and `Start` /
`Stop` buttons. **Starting a shaker begins physical agitation.** An optional 3D
model path and Z hint control how the accessory is drawn in the viewport.

### I/O

A read-only diagnostics view of the instrument's discrete signals, refreshed
from the live state stream:

- **Robot status** — robot disable (emergency stop) and motor power fault.
- **Head detection** — whether a head is attached, plus the configured head
  type and a `Refresh` button.
- **Go button** — whether the instrument's go button is pressed.
- **Plate detection** — whether a plate is sensed in the gripper.
- **Motor enable** — per-axis servo power for X, Y, Z and W.

This is the first place to look when an operation refuses to start. See
[troubleshooting](troubleshooting.md).

### Processes

The *Processes* tab runs one high-level operation at a time — the same
operations the workflow designer chains together, executed individually.

Choose a `Location` and confirm the `Labware` assigned there. The **2D
selector** draws the labware's well or tip grid, and is where tip-box pickup
regions are picked directly.

Under **Command parameters**, the `Command` dropdown selects the operation:
Aspirate, Dispense, Mix, Tips On, Tips Off, Stack Plates, Destack Plate, Mount
Plates, Unmount Plate, Delid Plate, Relid Plate, Scan Stack Height, or Read
Barcode. The properties panel below changes to match. `Execute Command` runs
it. **Every command in this list except Read Barcode causes motion.**

Property panels, by command:

- **Aspirate** — volume (µL), pre-aspirate volume, post-aspirate volume,
  liquid class, distance from well bottom (mm), dynamic tip extension (mm/µL),
  tip touch, pipette technique.
- **Dispense** — empty tips, volume (µL), blowout volume, liquid class,
  distance from well bottom (mm), dynamic tip retraction (mm/µL), tip touch,
  pipette technique.
- **Mix** — volume, pre-aspirate volume, blowout volume, liquid class, mix
  cycles, dynamic tip extension, aspirate distance, an optional separate
  dispense distance, tip touch, pipette technique.
- **Stack Plates** / **Mount Plates** — base location and source location,
  each showing the plate currently resolved there.
- **Destack Plate** / **Unmount Plate** — source stack location and
  destination pad.
- **Delid Plate** — plate location and lid destination.
- **Relid Plate** — lid location and plate location.
- **Scan Stack Height** — reports the configured plate, its stacking
  thickness, the measured height, the inferred plate count and the rounded
  stacking height.
- **Read Barcode** — reports the scan result.

Mount and Unmount are the stacking pair that also *locks* the two plates
together, so that a later pick-and-place transports both as a unit. Stack and
Destack move a single plate and leave the pair independent.

At the bottom, the **Head mode** panel shows the current head and its active
mode, with a `Set Head Mode` button that opens the head mode selector.

### Profiles

**Profile management** lists the profiles on disk. `Load` activates one,
`Save Settings` writes the current form back to the active profile, and
`Duplicate…` / `Rename…` manage the files. `Reinitialize` re-runs
initialization against the loaded profile — **this causes motion.** There are
also importers that read settings out of legacy instrument profile exports
(`.reg` files and `.dat` directory trees).

**Connection** selects the `Controller` type and its transport settings:

| Controller | Transport |
|---|---|
| Simulation | none |
| Agile (BioNet Ethernet) | Ethernet |
| Agile 7612 (Ethernet) | Ethernet |
| Bravo SRT (Ethernet) | Ethernet |
| Darwin (Ethernet) | Ethernet |
| Darwin (Serial) | serial port |

Ethernet controllers take an IP address, a machine ID and a device ID, and
offer `Find Available Device` — a discovery scan that lists the devices it can
see with their device ID, type, IP address, MAC address and status, optionally
restricted to one network adapter. Serial controllers take a port name.

**Miscellaneous** holds the safety and behaviour preferences: approach height,
Z safe position, whether to prompt for a W home on first initialization,
medium-speed operation, always moving to safe Z, ignoring the plate sensor
during pick and place, tips-off tip touch, and the deck-verification camera
settings.

**Head information** sets the installed `Head type` and whether to check the
head type on initialize. `Change Head Wizard` walks through a physical head
swap: it warns that the instrument will move to the highest point of location
5, then prompts you to power off, clear all labware, remove the old head,
select the newly installed head, power back on and finish. **The first step
causes motion.**

---

## Head modes and tip selection

A head with many barrels does not have to use all of them. The *head mode* is
the subset of barrels treated as active for tip pickup, tip return and liquid
handling. It is set from the head mode selector (*Processes* tab →
`Set Head Mode`) and read back through the live state.

The selector has three inputs:

- **Subset** — `All barrels`, `Single barrel`, `Full row`, `Full column`, or
  `Rectangle`.
- **Orientation** — which corner the subset is anchored to: front left, front
  right, back left, or back right. `All barrels` always anchors back left.
- **Count** — how many rows or columns (or, for a rectangle, both), shown only
  for the modes that need it.

A preview grid draws the active barrels and marks the anchor corner. Two
shortcuts sit beside it: `Suggest From Labware` proposes a mode based on the
installed head and the labware assigned at a location, and `Reset To All`
returns to the full head.

Head geometry follows the installed head type. The 384-barrel heads and the
384 pin tool are 16 × 24 on a 4.5 mm pitch; the 1536 pin tool is 32 × 48 on a
2.25 mm pitch; the 8- and 16-channel single-column heads are 8 × 1 and 16 × 1;
everything else is 8 × 12 on a 9 mm pitch. Modes that cannot apply to a given
geometry — a row subset on a single-column head, for instance — fall back to
all barrels.

The suggestion logic is straightforward: if the labware's well count matches
the head's channel count, use the full head; a 96-channel head on a 384-well
plate is suggested an 8 × 12 rectangle; an 8-channel head on a 96- or 384-well
plate is suggested a full column; a 16-channel head on a 384-well plate is
suggested a full row.

**Tip selection** is the companion setting: which block of a tip box lines up
with the active subset of the head. It is chosen from the 2D selector on the
*Processes* tab, and is validated against head mode, tip-box geometry and the
box's current inventory. The rules are:

- The selected block must match the active subset's row and column counts.
- For pickup, every well in the block must still hold a tip.
- For return, every well in the block must be empty.
- No tips may remain beyond the block on the side the head approaches from, so
  that partial boxes are consumed from one corner inward rather than leaving
  the head straddling occupied wells.

The selector only offers anchors that satisfy all of these, so an illegal
selection cannot be made by clicking. Full-head modes always anchor at the
back-left corner and need no selection.

Head mode and tip selection persist as instrument state: whatever is set here
applies to subsequent tip and liquid-handling operations until it is changed.

---

## Deck model and labware

The deck is nine locations in a 3 × 3 grid, numbered 1–9. Each location holds
a stack of labware — usually one plate, sometimes a plate with a lid, a plate
mounted on another plate, or a taller stack built by repeated stacking
operations.

Labware definitions come from the catalog managed at `/labware-editor`. The
dashboard has two views, **Labware Entries** and **Labware Classes**. An entry
is edited across several tabs:

- **Plate Properties** — physical dimensions and stacking geometry.
- **Pipette/Well Definition** — the well grid and per-well geometry used to
  compute pipetting positions.
- **Image** — a 2D image asset for the UI.
- **PF400** and **Planar Motor** — gripper and transport parameters for those
  integrations.

Labware classes group compatible entries, which is how lid and plate
compatibility is expressed.

Assigning labware to a location, in either the control panel's *Config* tab or
the designer's deck panel, records the definition plus whether the item is
lidded or sealed, and for tip boxes which tip definition it holds.

---

## Tips, liquid classes and pipette techniques

**Tip definitions** are edited at `/tip-editor`. Each definition has a tip ID,
a display label, a nominal volume in µL, a tip length in mm, an optional 3D
model path, a source field, and the list of heads it is compatible with. Tip
length feeds directly into teaching and into every Z position the software
computes, so it has to be right.

**Liquid classes** are edited at `/liquid-class-editor`. A liquid class is
resolved against a context — machine ID, head type, tip definition and tip
capacity — shown at the top of the editor, so the same class name can carry
different tuning on different instruments or with different tips. Each class
has a name and notes plus three tabs:

- **Aspirate** — plunger velocity, acceleration and post-delay, and the Z-axis
  velocities and accelerations for moving into and out of the liquid.
- **Dispense** — the same set of parameters for the dispense stroke. A
  `Copy values to dispense` / `Copy values to aspirate` button moves settings
  between the two.
- **Equation** — the volume-correction relationship, with a
  `Reset to identity` button.

Changes are committed with `Save changes` or `Save changes as…`.

**Pipette techniques** are managed in the same page. A technique is a reusable
motion pattern layered on top of an aspirate or dispense: a radius in mm, a
number of segments, the Z phase it applies to (entering the liquid, exiting,
or both), a direction, and flags for whether it applies on aspirate, on
dispense, or both. Techniques are referenced by name from any operation that
accepts one, which keeps motion tuning out of individual commands.

Both liquid classes and pipette techniques are validated before a workflow
runs: a reference to a name that does not exist in the current tip and head
context stops the run before any motion, and names the offending nodes.

---

## Live state readout

The control panel subscribes to a WebSocket state stream at `/ws/state`, and
the same snapshot is available as a single request from `GET /api/state`. It
updates roughly 30 times a second in simulation and about five times a second
on hardware, where reads are throttled to avoid competing with motion.

The snapshot carries:

- **Connection** — `connected`, `initialized`, `controller_type`,
  `machine_id`.
- **Motion** — `positions` for every available axis, `motors_enabled` per
  axis, `engine_busy`, and `teachpoints` for all nine locations.
- **Head and tips** — `head_type`, `head_attached`, `head_mode`,
  `tip_selection`, `plate_selection`, plus `tips_on_head`,
  `tips_on_head_mode` and `tips_on_head_selection` describing what is
  physically on the head right now, and `active_tip_id`,
  `active_tip_capacity_ul`, `tip_labware`, `tip_definition_id` and
  `attached_tip_length_mm` describing which tip definition is in play.
- **Deck** — `deck` (labware names per location), `deck_details` (full
  metadata, including whether each item is mounted to the one below it), and
  `tipbox_inventory`.
- **Discretes** — `go_button_pressed`, `plate_in_gripper`, `robot_disabled`.
- **Task** — `task_status` with the running task's current step name, step
  index, step count, status, and error details when a step has failed.
- **Telemetry** — controller-specific diagnostic values.

Full field-by-field documentation is in the [API reference](api-reference.md).

---

## Operator prompts

Some failures pause the run and wait for a decision rather than aborting:

- **Operator action required** — a task step failed. The choices are `Retry`
  (run the step again), `Ignore` (skip it and continue), and `Abort`. Ignoring
  a failed step continues with an instrument in a state the software may no
  longer be tracking correctly; prefer retry or abort unless you understand
  exactly what was skipped.
- **Pickup verification failed** — the gripper may not have acquired a plate.
  The choices are `Retry Pickup`, `Ignore And Continue`, and `Abort`.
- **Process blocked** — the requested move would overlap occupied neighbouring
  deck positions. The dialog reports the command, the head mode, the allowed
  top plane, and a grid of the conflicting positions. This is a pre-motion
  check: nothing has moved. Fix the deck assignment or the head mode and try
  again.

The workflow designer surfaces the same prompts during a run, along with two of
its own for Script nodes — see [workflows](workflows.md).

---

## Where to go next

- [Workflows](workflows.md) — building and running multi-step protocols.
- [Configuration](configuration.md) — profiles, environment variables, files.
- [Hardware setup](hardware-setup.md) — networking, discovery, teaching.
- [API reference](api-reference.md) — driving all of this from code.
- [Architecture](architecture.md) — how the pieces fit together.
- [Troubleshooting](troubleshooting.md) and [FAQ](faq.md).

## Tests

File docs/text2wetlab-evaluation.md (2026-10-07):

# Text2WetLab evaluation boundary

Status checked on 2026-10-07 against
[Text2WetLab](https://huggingface.co/datasets/EvanOLeary/Text2WetLab) revision
d7c8a9b93428997447eeaf2ee9e27ac3ce026872 and the saved local reports below. The seven public
Harbor tasks require **Opentrons OT-2 Python API v2** protocols on task-specific fixed
decks. Their verifier applies anti-hack checks, separate static lint where supplied,
Opentrons 7.5.0 simulation, a run log, and a five-item rubric judged from the run. The RNA
task embeds its rubric in tests/grade.py and has no separate protocol_lint.py. The dataset's
six-check PyLabRobot gym is a different evaluation; its result cannot be added to the Harbor
score.

The requested 100% means **35/35 Harbor rubric items across all seven tasks** under the
dataset's actual verifier. The local runner has **no official Harbor score** (official_score
is null). Docker Desktop was started on 2026-10-07, and pinned container checks now run;
`ANTHROPIC_API_KEY` remains unset, so the rubric judge cannot run. A local simulator or
pre-judge container pass does not substitute for the complete official verifier. All protocol
candidates in this effort
are authored by the local Qwen model at http://sparky.local:8000/v1; pyBravo supplies source
material, prompts, validators, and storage, not hand-written protocol answers.

## Two distinct outputs

The OT-2 adapter in pybravo/evals/text2wetlab/ is a benchmark harness. It generates OT-2
Python candidates for the pinned tasks and checks them in an isolated Opentrons environment.
Those files are **not Bravo protocols**. A passing OT-2 simulation says the candidate is
API-compatible and survived the local mechanical checks; it does not establish scientific
fidelity or Bravo hardware readiness.

Separately, Qwen has authored **seven saved, loadable pyBravo Designer drafts**, one for
each task. scripts/generate_text2wetlab_designer.py saves the model's primitive-node DAG,
exact source digests, and review issues through /api/protocols/generated-drafts; each saved
workflow opens with /designer?workflow=<workflow_id>. The local generation report is
/tmp/pybravo-text2wetlab-designer/report.json. All seven are marked unreviewed; Designer
disables Simulate and Execute for them. They are inspectable starting points, not completed
or approved Bravo methods. Their current issues include unavailable liquid classes,
unverified tip-box and deck substitutions, omitted sample mappings, and, in the RNA draft,
unaccounted elution recovery. OT-2 deck slots and external modules cannot be copied onto
Bravo as hardware facts.

The earlier 3,107-check readiness screen showed how a compact intent can expand into
thousands of per-well questions. A saved DAG does not resolve those questions. Before a
Bravo run, the selected head, tips, rack inventory, labware, liquid method, heights, deck,
repeated-well mapping, external handoffs, strict simulation, and scientist approval still
need to agree. Draft review issues are grouped diagnostics, not a release decision.

## Local evidence snapshot

These are outcomes from **separate saved runs**, not one simultaneous seven-task evaluation
with the current code. Six distinct tasks reached the independent static/lint, Opentrons
simulation, run-log, and event-safety gates at least once. Provenance-checked replays of
four older Qwen-authored candidates plus the newer colony run give **5/7 tasks with complete
local mechanical evidence** under the current audit. The newer scientific-coverage gate
makes Golden Gate a known failure despite its older report's simulator_passed status. All
five local acceptances still have needs_review scientific or manual-stage checks; none has
an official score.

| Task | Saved local mechanical evidence | Outstanding scientific or generation issue |
| --- | --- | --- |
| A1–A12 100 µL transfer | Current pinned recheck passed | Task fidelity still needs review; Bravo draft remains unreviewed. |
| Split 200 µL between two wells | Current pinned recheck passed | Task fidelity still needs review; Bravo draft remains unreviewed. |
| AMPure cleanup | Current pinned recheck passed with sample-isolated fresh tips | Physical tip replenishment, binding/wash/drying handoffs, and contamination need review. |
| E. coli heat shock | Current pinned recheck passed after a Qwen line repair put the 37 °C transition before SOC additions | Paper fidelity and external-module stages still require review. |
| Golden Gate assembly | Older saved report passed mechanical gates | Its embedded local rubric audit **failed** required PCR setup and ordered DpnI/cleanup handoffs. Current adapter rejects observable audit failures; the saved report predates that gate. |
| Colony PCR | A newer Qwen draft passed current local lint, simulation, pinned run log, and event-safety gates | Primer-stock concentration was not specified, the 4 µL primer-pair choice needs scientific review, and tip replenishment requires an explicit operator handoff before physical use. |
| RNA extraction | No accepted local simulation | Fresh drafts exceeded the effective 200 µL filter-tip capacity or exhausted installed tips; 48-sample mapping and elution recovery remain unresolved. |

The provenance-checked current recheck reports are in
/tmp/pybravo-text2wetlab-a1-current-timed/,
/tmp/pybravo-text2wetlab-split-current-timed/,
/tmp/pybravo-text2wetlab-ampure-current-timed2/,
/tmp/pybravo-text2wetlab-ecoli-current-timed/, and
/tmp/pybravo-text2wetlab-colony-current-timed/. Their `generation` field is null: each
recheck verified the original Qwen trace and protocol digest, then applied the current
pinned gates without asking the model to regenerate a protocol. Other reports are in
/tmp/pybravo-text2wetlab-golden-planning/, /tmp/pybravo-text2wetlab-golden-direct5/,
/tmp/pybravo-text2wetlab-colony-current2/, and
/tmp/pybravo-text2wetlab-rna-current2/. Each report and task trace records its own code and
source hashes, attempts, and gate results. The Golden Gate report contains
local_rubric_audit.status: failed even though its top-level status is the older
simulator_passed; the latter must not be counted as current scientific acceptance. A later
evidence-planning rerun in /tmp/pybravo-text2wetlab-golden-science-gated/ timed out at the
local Qwen 300-second limit before saving a plan or reaching simulation. A direct-draft
science-gated rerun also failed: Qwen repaired tip isolation but overfilled a cited 25 µL
PCR and did not produce an accepted ordered handoff sequence.

The read-only aggregate audit is
`/tmp/pybravo-text2wetlab-current-timed-evidence-audit.json`. It confirms the five
mechanical-evidence tasks above; Golden Gate has failed observable science checks and RNA
has no accepted local report. It cannot run the official anti-hack gate or rubric judge.

The **unchanged pinned `tests/test.sh`** has now also run inside task-specific Docker images
for six saved Qwen candidates. A1–A12, split, AMPure, E. coli, colony PCR, and the older
Golden Gate candidate all passed that container's lint, anti-hack, and simulation gates.
Golden Gate remains rejected by the separate local scientific audit. In all six container
runs the judge returned an authentication error because no Anthropic key was supplied;
its zero `reward` is therefore **not** a judged rubric score. Candidate digests, pinned
test/Dockerfile hashes, verdicts, and verifier paths are recorded in
`/tmp/pybravo-text2wetlab-official-container-summary-all.json`. RNA has no accepted
candidate to check. No official 35-item claim follows from these pre-judge passes.

## How the current local harness stays grounded

When a paper is supplied, prepare_scientific_source() selects a **verbatim Methods passage
and up to two task-relevant Results subsections** if they fit the input budget; otherwise it
retains the full source. The trace records selection strategy, original and excerpt SHA-256
digests, and line spans. Excerpt selection reduces irrelevant context but can omit a
pertinent passage, so paper fidelity remains a review item. The heat-shock paper is absent
from the dataset checkout and must be supplied with its pinned digest
(768a5703630e593a3eb5be8cac6267af0cf26ba1b43dbc797d24b08cbaf3f18a).

Optional --evidence-planning first asks Qwen for a typed plan with citations to the task or
supplied source. Deterministic checks cover source inventory, intermediate production order,
final reaction volume, stock dilution, single-stroke pipette ranges, tip demand and refill
permission, multichannel geometry, and module state before dependent pipetting. Failed plans
receive bounded correction feedback and are retained as planning_attempt_*.json. If no plan
passes, generation falls back to the original source and the trace says so; fallback is not
evidence that a plan was validated. In the saved colony run, the second plan passed the
**older** checks but its code exhausted tips. The planner now also requires each robot
addition to name an executable pipette stage and each such stage to have tip demand. Both
Golden Gate planning attempts failed citation grounding and its saved code generation fell
back to source text.

The adapter applies static source limits, the independent Opentrons simulator, structured
tip/volume/event checks, and bounded Qwen repairs. A focused line patch may correct a
mechanical error only if its source guard preserves liquid actions, relevant locations, deck
bindings, timed commands, and tip safety; the patched candidate is checked again. Explicit
task permission is required for a tip-rack reset. This repair mechanism does not invent
missing chemistry or approve a liquid method.

The read-only local_rubric_audit inspects **observable** facts for the seven tasks and
retains supported, failed, or needs_review for each of the 35 rubric items. The current
adapter rejects observable failures and gives Qwen feedback grounded only in the task or
paper passages. It does not disclose judge wording as a generation instruction, certify
paper interpretation, grade manual stages, or compute an official score. Golden Gate
demonstrates why this extra gate matters: the simulator observed valid pipette events while
required scientific content was missing.

## Reproduce the local checks

Create the isolated simulator environment matching the pinned Dockerfile:

~~~sh
python3.10 -m venv /tmp/pybravo-text2wetlab-ot2-py310
/tmp/pybravo-text2wetlab-ot2-py310/bin/pip install \
  'opentrons==7.5.0' 'opentrons-shared-data==7.5.0' 'pydantic<2'
/tmp/pybravo-text2wetlab-ot2-py310/bin/opentrons_simulate --version
~~~

Run selected pinned tasks; each output directory is a fresh local experiment. The runner
checks only selected tasks, records hashes, and leaves official_score null:

~~~sh
.venv/bin/python scripts/evaluate_text2wetlab.py \
  --task a1-a12-100ul --task split-200ul-two-wells \
  --simulator /tmp/pybravo-text2wetlab-ot2-py310/bin/opentrons_simulate \
  --output-dir /tmp/pybravo-text2wetlab-check
~~~

To recheck an existing Qwen-authored candidate without a new model call, pass the saved
run directory with `--recheck-from` and use a new output directory. For example:

~~~sh
.venv/bin/python scripts/evaluate_text2wetlab.py \
  --task split-200ul-two-wells \
  --recheck-from /tmp/pybravo-text2wetlab-split-baseline \
  --dataset-root /tmp/Text2WetLab-eval \
  --simulator /tmp/pybravo-text2wetlab-ot2-py310/bin/opentrons_simulate \
  --output-dir /tmp/pybravo-text2wetlab-split-recheck
~~~

For a task with a supplied paper, add --evidence-planning to inspect the typed plan and its
audit before code generation. For E. coli, also pass --paper-override
ecoli-heat-shock-transformation=/path/to/pinned-paper.txt; the runner rejects a digest
mismatch. The RNA runner supplies its pinned custom labware to both generation and
simulation, and marks separate lint not_applicable rather than treating the missing lint
file as a pass.

To repeat the pinned container's pre-judge gates on an unchanged saved Qwen candidate, use
the verifier runner with an exact Git checkout of the pinned dataset. It verifies the checkout
and candidate provenance, builds that task's unchanged Dockerfile, runs `tests/test.sh` with
fresh logs and no protocol network access, and writes a `summary.json` with separate lint,
anti-hack, simulation, and judge fields. The default run supplies no judge key:

~~~sh
.venv/bin/python scripts/verify_text2wetlab_container.py \
  --task split-200ul-two-wells \
  --saved-run-root /tmp/pybravo-text2wetlab-split-baseline \
  --candidate /tmp/pybravo-text2wetlab-split-baseline/split-200ul-two-wells/protocol.py \
  --dataset-root /tmp/Text2WetLab-eval \
  --output-dir /tmp/pybravo-text2wetlab-split-container-repeat
~~~

An explicit `--judge` uses `ANTHROPIC_API_KEY` from the environment, if configured; it
records the returned local rubric separately and still leaves `official_score` null. The
local Docker network policy in judge mode is not Harbor's allowlist, so this remains a
reproduction aid rather than a Harbor-issued score.

With pyBravo running locally, inspect one already saved Designer draft's review issues
without creating a new protocol or calling Qwen:

~~~sh
.venv/bin/python scripts/repair_text2wetlab_designer.py \
  --task golden-gate-assembly \
  --api-url http://127.0.0.1:8000 \
  --output-dir /tmp/pybravo-text2wetlab-designer-audit
~~~

--run invokes local Qwen for bounded graph repair and saves a **new unreviewed draft** only
when the repair passes its checks; it never approves a workflow. Routine regression checks
are:

~~~sh
.venv/bin/pytest -q tests/test_text2wetlab_runner.py \
  tests/test_text2wetlab_planning.py tests/test_text2wetlab_rubric_audit.py \
  tests/test_text2wetlab_designer_generator.py tests/test_scientific_patterns.py
~~~

An official 100% claim still needs seven accepted protocols run through the pinned Harbor
verifier and 35/35 judged rubric items. A separate Bravo claim needs seven scientifically
reviewed Designer graphs that validate and strictly simulate against a confirmed Bravo
profile, inventory, and liquid methods. Neither milestone has been reached.

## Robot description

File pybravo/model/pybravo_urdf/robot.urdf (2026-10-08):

<?xml version="1.0" ?>
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
<robot name="robot">
  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
  <link name="base_link">
    <inertial>
      <origin xyz="0 0 0" rpy="0 0 0"/>
      <mass value="1e-09"/>
      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
    </inertial>
  </link>
  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
  <link name="hw1_300_001">
    <inertial>
      <origin xyz="0 0 0" rpy="0 0 0"/>
      <mass value="1e-09"/>
      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
    </inertial>
  </link>
  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
  <link name="hw1_300_001_hw1_300_001">
    <inertial>
      <origin xyz="0 0 0" rpy="0 0 0"/>
      <mass value="1e-09"/>
      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
    </inertial>
    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
  </link>
  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
  <joint name="hw1_300_001_hw1_300_001_fixed" type="fixed">
    <origin xyz="-0.18669 0.109093 0.023015" rpy="-1.5708 1.60971e-15 3.14159"/>
    <parent link="hw1_300_001"/>
    <child link="hw1_300_001_hw1_300_001"/>
    <axis xyz="0 0 1"/>
    <limit effort="10" velocity="10"/>
  </joint>
  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
  <joint name="base_link_to_hw1_300_001" type="fixed">
    <origin xyz="0 0 0" rpy="0 -0 0"/>
    <parent link="base_link"/>
    <child link="hw1_300_001"/>
    <axis xyz="0 0 1"/>
    <limit effort="10" velocity="10"/>
  </joint>
  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
  <link name="part_4">
    <inertial>
      <origin xyz="0 0 0" rpy="0 0 0"/>
      <mass value="1e-09"/>
      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
    </inertial>
  </link>
  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
  <link name="xgantry">
    <inertial>
      <origin xyz="0 0 0" rpy="0 0 0"/>
      <mass value="1e-09"/>
      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
    </inertial>
  </link>
  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
  <link name="ygantry">
    <inertial>
      <origin xyz="0 0 0" rpy="0 0 0"/>
      <mass value="1e-09"/>
      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
    </inertial>
  </link>
  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
  <link name="384_head">
    <inertial>
      <origin xyz="0 0 0" rpy="0 0 0"/>
      <mass value="1e-09"/>
      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
    </inertial>
  </link>
  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
  <link name="384_head_384_head">
    <inertial>
      <origin xyz="0 0 0" rpy="0 0 0"/>
      <mass value="1e-09"/>
      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
    </inertial>
    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
  </link>
  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
  <joint name="384_head_384_head_fixed" type="fixed">
    <origin xyz="-1.01371e-05 -0.00832231 -0.08" rpy="0 3.65358e-43 0"/>
    <parent link="384_head"/>
    <child link="384_head_384_head"/>
    <axis xyz="0 0 1"/>
    <limit effort="10" velocity="10"/>
  </joint>
  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
  <joint name="zaxis" type="prismatic">
    <origin xyz="-0.00442215 0.0427703 -0.0615" rpy="-1.5708 5.08796e-29 -1.42074e-14"/>
    <parent link="ygantry"/>
    <child link="384_head"/>
    <axis xyz="0 0 1"/>
    <limit effort="10" velocity="10" lower="-0.105" upper="0"/>
  </joint>
  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
  <link name="gripperzaxis">
    <inertial>
      <origin xyz="0 0 0" rpy="0 0 0"/>
      <mass value="1e-09"/>
      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
    </inertial>
  </link>
  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
  <link name="fingerleft">
    <inertial>
      <origin xyz="0 0 0" rpy="0 0 0"/>
      <mass value="1e-09"/>
      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
    </inertial>
  </link>
  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
  <link name="fingerleft_fingerleft">
    <inertial>
      <origin xyz="0 0 0" rpy="0 0 0"/>
      <mass value="1e-09"/>
      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
    </inertial>
    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
  </link>
  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
  <joint name="fingerleft_fingerleft_fixed" type="fixed">
    <origin xyz="0.0640098 0.000645594 -4.70103e-33" rpy="1.5708 -0 2.07332e-76"/>
    <parent link="fingerleft"/>
    <child link="fingerleft_fingerleft"/>
    <axis xyz="0 0 1"/>
    <limit effort="10" velocity="10"/>
  </joint>
  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
  <joint name="ygripper-left" type="prismatic">
    <origin xyz="-0.0619736 0.051 0.012" rpy="1.5708 2.94796e-38 4.45369e-45"/>
    <parent link="gripperzaxis"/>
    <child link="fingerleft"/>
    <axis xyz="0 0 1"/>
    <limit effort="10" velocity="10" lower="-1.73472e-18" upper="0.021"/>
  </joint>
  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
  <link name="fingerright">
    <inertial>
      <origin xyz="0 0 0" rpy="0 0 0"/>
      <mass value="1e-09"/>
      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
    </inertial>
  </link>
  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
  <link name="fingerright_fingerright">
    <inertial>
      <origin xyz="0 0 0" rpy="0 0 0"/>
      <mass value="1e-09"/>
      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
    </inertial>
    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
  </link>
  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
  <joint name="fingerright_fingerright_fixed" type="fixed">
    <origin xyz="0.0640098 -0.000645578 -0.004" rpy="-1.5708 -0 1.66327e-77"/>
    <parent link="fingerright"/>
    <child link="fingerright_fingerright"/>
    <axis xyz="0 0 1"/>
    <limit effort="10" velocity="10"/>
  </joint>
  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
  <joint name="ygripper-right" type="prismatic">
    <origin xyz="-0.0619736 -0.051 0.012" rpy="-1.5708 -2.58023e-38 -4.6314e-45"/>
    <parent link="gripperzaxis"/>
    <child link="fingerright"/>
    <axis xyz="0 0 1"/>
    <limit effort="10" velocity="10" lower="-0.009" upper="0.012"/>
    <mimic joint="ygripper-left" multiplier="1.0"/>
  </joint>
  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
  <link name="gripperzaxis_gripperzaxis">
    <inertial>
      <origin xyz="0 0 0" rpy="0 0 0"/>
      <mass value="1e-09"/>
      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
    </inertial>
    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
  </link>
  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
  <joint name="gripperzaxis_gripperzaxis_fixed" type="fixed">
    <origin xyz="-0.00847357 -6.10859e-09 -0.165" rpy="3.14159 6.65579e-61 0"/>
    <parent link="gripperzaxis"/>
    <child link="gripperzaxis_gripperzaxis"/>
    <axis xyz="0 0 1"/>
    <limit effort="10" velocity="10"/>
  </joint>
  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
  <joint name="zaxis-gripper" type="prismatic">
    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
    <origin xyz="0.078228 -0.224926 -0.0530846" rpy="1.5708 8.63559e-42 -5.71589e-35"/>
    <parent link="ygantry"/>
    <child link="gripperzaxis"/>
    <axis xyz="0 0 1"/>
    <limit effort="10" velocity="10" lower="0" upper="0.17"/>
  </joint>
  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
  <link name="ygantry_ygantry">
    <inertial>
      <origin xyz="0 0 0" rpy="0 0 0"/>
      <mass value="1e-09"/>
      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
    </inertial>
    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
  </link>
  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
  <joint name="ygantry_ygantry_fixed" type="fixed">
    <origin xyz="0.0905 0.0500739 -0.0530846" rpy="-1.5708 -0 2.13433e-117"/>
    <parent link="ygantry"/>
    <child link="ygantry_ygantry"/>
    <axis xyz="0 0 1"/>
    <limit effort="10" velocity="10"/>
  </joint>
  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
  <joint name="yaxis" type="prismatic">
    <origin xyz="0.211024 0.451844 -0.294946" rpy="-2.47011e-76 -1.5708 0"/>
    <parent link="xgantry"/>
    <child link="ygantry"/>
    <axis xyz="0 0 1"/>
    <limit effort="10" velocity="10" lower="-0.01" upper="0.21"/>
  </joint>
  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
  <link name="xgantry_xgantry">
    <inertial>
      <origin xyz="0 0 0" rpy="0 0 0"/>
      <mass value="1e-09"/>
      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
    </inertial>
    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
  </link>
  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
  <joint name="xgantry_xgantry_fixed" type="fixed">
    <origin xyz="-0.0139762 0.255699 -0.276621" rpy="-1.5708 -1.5708 0"/>
    <parent link="xgantry"/>
    <child link="xgantry_xgantry"/>
    <axis xyz="0 0 1"/>
    <limit effort="10" velocity="10"/>
  </joint>
  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
  <joint name="xaxis" type="prismatic">
    <origin xyz="0.28829 -0.157773 -0.0235762" rpy="1.5708 -0 1.5708"/>
    <parent link="part_4"/>
    <child link="xgantry"/>
    <axis xyz="0 0 1"/>
    <limit effort="10" velocity="10" lower="-0.176058" upper="0.218942"/>
  </joint>
  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
  <link name="part_4_part_4">
    <inertial>
      <origin xyz="0 0 0" rpy="0 0 0"/>
      <mass value="1e-09"/>
      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
    </inertial>
    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
  </link>
  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
  <joint name="part_4_part_4_fixed" type="fixed">
    <origin xyz="0 0 0" rpy="0 -0 0"/>
    <parent link="part_4"/>
    <child link="part_4_part_4"/>
    <axis xyz="0 0 1"/>
    <limit effort="10" velocity="10"/>
  </joint>
  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
  <joint name="base_link_to_part_4" type="fixed">
    <origin xyz="0 0 0" rpy="0 -0 0"/>
    <parent link="base_link"/>
    <child link="part_4"/>
    <axis xyz="0 0 1"/>
    <limit effort="10" velocity="10"/>
  </joint>
  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
  <link name="hw1_300_001_2">
    <inertial>
      <origin xyz="0 0 0" rpy="0 0 0"/>
      <mass value="1e-09"/>
      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
    </inertial>
  </link>
  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
  <link name="hw1_300_001_2_hw1_300_001_2">
    <inertial>
      <origin xyz="0 0 0" rpy="0 0 0"/>
      <mass value="1e-09"/>
      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
    </inertial>
    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
  </link>
  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
  <joint name="hw1_300_001_2_hw1_300_001_2_fixed" type="fixed">
    <origin xyz="0 0.109093 0.023015" rpy="-1.5708 1.60971e-15 3.14159"/>
    <parent link="hw1_300_001_2"/>
    <child link="hw1_300_001_2_hw1_300_001_2"/>
    <axis xyz="0 0 1"/>
    <limit effort="10" velocity="10"/>
  </joint>
  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
  <joint name="base_link_to_hw1_300_001_2" type="fixed">
    <origin xyz="0 0 0" rpy="0 -0 0"/>
    <parent link="base_link"/>
    <child link="hw1_300_001_2"/>
    <axis xyz="0 0 1"/>
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

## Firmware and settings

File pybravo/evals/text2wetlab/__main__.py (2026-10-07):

"""CLI for generating an OT-2 benchmark protocol in one task directory."""

from __future__ import annotations

import argparse
import asyncio
import json
import sys
from dataclasses import replace
from pathlib import Path

from pybravo.workflow.protocols.llm import LocalLLMConfig

from .adapter import generate_ot2_protocol


def main(argv: list[str] | None = None) -> int:
    parser = argparse.ArgumentParser(description=__doc__)
    parser.add_argument("--task-dir", type=Path, required=True, help="Sole directory for protocol.py and generation_trace.json")
    parser.add_argument("--instruction-file", type=Path, help="Task instruction; defaults to TASK_DIR/instruction.md")
    parser.add_argument("--paper-file", type=Path, help="Optional additional scientific source supplied with the task")
    parser.add_argument("--simulator-command", help="Path or executable name for opentrons_simulate")
    parser.add_argument("--event-logger", type=Path,
                        help="Task's pinned structured runlog.py; required when simulation runs")
    parser.add_argument("--labware-dir", type=Path,
                        help="Optional directory of task-supplied custom Opentrons labware definitions")
    parser.add_argument("--simulation-timeout", type=float, default=180)
    parser.add_argument("--repair-attempts", type=int, default=2)
    parser.add_argument("--patch-attempts", type=int, default=1,
                        help="Bounded local line-edit repairs after an event-safety failure (0–3)")
    parser.add_argument("--rubric-task",
                        help="Optional pinned task ID for read-only observable scientific checks")
    parser.add_argument("--evidence-planning", action="store_true",
                        help="Ask the same local model for a cited plan and audit it before code generation")
    parser.add_argument("--planning-attempts", type=int, default=2,
                        help="Maximum local-model attempts to ground and audit the optional plan (1–3)")
    parser.add_argument("--model-base-url", help="OpenAI-compatible local model server URL")
    parser.add_argument("--model", help="Model alias on the local server")
    parser.add_argument("--model-timeout", type=float, default=300,
                        help="Per-request local model timeout in seconds (default: 300)")
    parser.add_argument("--max-output-tokens", type=int, default=16_000,
                        help="Maximum local model response tokens (default: 16000)")
    args = parser.parse_args(argv)

    instruction_path = args.instruction_file or args.task_dir / "instruction.md"
    try:
        instruction = instruction_path.read_text(encoding="utf-8")
        source = args.paper_file.read_text(encoding="utf-8") if args.paper_file else None
        config = LocalLLMConfig.from_env()
        if args.model_base_url is not None:
            config = replace(config, base_url=args.model_base_url)
        if args.model is not None:
            config = replace(config, model=args.model)
        # Transport retries on a timed-out generation repeat the same expensive
        # call without any new diagnostic. Repair attempts follow model output.
        config = replace(config, timeout_s=args.model_timeout,
                         max_tokens=args.max_output_tokens, retries=0)
        result = asyncio.run(generate_ot2_protocol(
            instruction,
            args.task_dir,
            scientific_source=source,
            config=config,
            simulator_command=args.simulator_command,
            event_logger_path=args.event_logger,
            labware_dir=args.labware_dir,
            repair_attempts=args.repair_attempts,
            patch_attempts=args.patch_attempts,
            rubric_task=args.rubric_task,
            evidence_planning=args.evidence_planning,
            planning_attempts=args.planning_attempts,
            simulation_timeout_s=args.simulation_timeout,
        ))
    except (OSError, RuntimeError, ValueError) as exc:
        print(f"OT-2 benchmark generation failed: {exc}", file=sys.stderr)
        return 1
    print(json.dumps({
        "protocol_path": str(result.protocol_path),
        "trace_path": str(result.trace_path),
        "attempts": result.attempts,
        "simulation": result.simulation.status,
    }))
    return 0


if __name__ == "__main__":
    raise SystemExit(main())

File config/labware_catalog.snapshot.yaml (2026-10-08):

# dead_volume_ul values below are unreviewed review placeholders, not validated
# Bravo aspiration limits. See docs/labware_dead_volume_review.md.
version: 1
source: local_editor
synced_at: '2026-07-27T22:56:23.489616+00:00'
labware:
- id: lw-3918306f45b8
  name: 1536 Labcyte LP-0400 LDV
  kind: sbs_plate
  vendor: ''
  catalog_number: ''
  description: ''
  base_class: microplate
  wells: 1536
  length_mm: 127.76
  width_mm: 85.48
  height_mm: 10.48
  stack_height_mm: 9.8
  gripper_offset_mm: 1.0
  lid_gripper_offset_mm: null
  empty_check_offset_mm: null
  shim_thickness_mm: 0.0
  can_be_sealed: true
  sealed_height_mm: 10.5
  sealed_stacking_height_mm: 9.3
  can_have_lid: false
  lidded_height_mm: 0.0
  lidded_stack_height_mm: 0.0
  lid_resting_height_mm: 0.0
  lid_departure_height_mm: 0.0
  max_robot_handling_speed: fast
  rows: 32
  cols: 48
  well_depth_mm: 5.2
  offset_x_mm: 3.375
  offset_y_mm: 3.375
  spacing_x_mm: 2.25
  spacing_y_mm: 2.25
  well_volume_ul: 5.5
  dead_volume_ul: 0.3
  dead_volume_status: placeholder
  well_diameter_mm: 1.7
  well_geometry: square
  disposable_tip_capacity_ul: 10.0
  tip_definition_id: ''
  supported_tip_ids: []
  model_3d: /labware-assets/lw-3918306f45b8/1536_Labcyte_LP-0400_LDV.gltf
  can_mount: false
  can_be_mounted: false
- id: lw-34358f93e2a0
  name: 384 CellVis 1.5H
  kind: sbs_plate
  vendor: Cellvis
  catalog_number: P384-1.5H-N
  description: ''
  base_class: microplate
  wells: 384
  length_mm: 127.6
  width_mm: 85.6
  height_mm: 14.33
  stack_height_mm: 14.3
  gripper_offset_mm: 8.0
  lid_gripper_offset_mm: 0.5
  empty_check_offset_mm: null
  shim_thickness_mm: 0.0
  can_be_sealed: false
  sealed_height_mm: 0.0
  sealed_stacking_height_mm: 0.0
  can_have_lid: true
  lidded_height_mm: 16.8
  lidded_stack_height_mm: 17.7
  lid_resting_height_mm: 6.8
  lid_departure_height_mm: 11.0
  lid_geometry:
    model: manufacturer_exterior_envelope
    length_mm: 127.15
    width_mm: 85.05
    height_mm: 10.0
    seated_bottom_mm: 6.8
    source: https://www.cellvis.com/images/glass_bottom_plate_384_well_size.png
    source_document: docs/media/cellvis-384-plate-lid-dimensions.png
    source_sha256: 3ca5ca8dcf5f6aff0c44d32f66796c478ce66119c149fbcc250cef7d0f423985
    source_note: Official Cellvis dimension diagram supplied by user; seated bottom = 16.8 - 10.0 mm.
    limitations:
    - Wall thickness, internal clearance and corner chamfers are not dimensioned.
  max_robot_handling_speed: fast
  rows: 16
  cols: 24
  well_depth_mm: 11.38
  offset_x_mm: 2.25
  offset_y_mm: 2.25
  spacing_x_mm: 4.5
  spacing_y_mm: 4.5
  well_volume_ul: 0.0
  dead_volume_ul: 5.0
  dead_volume_status: placeholder
  well_diameter_mm: 3.3
  well_geometry: square
  disposable_tip_capacity_ul: 0.0
  tip_definition_id: ''
  supported_tip_ids: []
  model_3d: /labware-assets/lw-34358f93e2a0/Cellvis_P384_1.5H_N.glb
  can_mount: false
  can_be_mounted: false
- id: 01KD4PYY7N4EG0E22P3QP1RHB9
  name: 384 Labcyte PP0200 PP sq flt
  kind: sbs_plate
  vendor: Beckman
  catalog_number: 001-14622
  description: Echo(R) Qualified 384-Well Polypropylene Microplate, Clear, Sterile,
    Surface-treated with Amine Coating
  base_class: microplate
  wells: 384
  length_mm: 127.76
  width_mm: 85.48
  height_mm: 14.4
  stack_height_mm: 13.6
  gripper_offset_mm: 7.0
  lid_gripper_offset_mm: null
  empty_check_offset_mm: null
  shim_thickness_mm: 4.0
  can_be_sealed: true
  sealed_height_mm: 0.0
  sealed_stacking_height_mm: 0.0
  can_have_lid: true
  lidded_height_mm: 16.5
  lidded_stack_height_mm: 14.5
  lid_resting_height_mm: 9.5
  lid_departure_height_mm: 8.5
  max_robot_handling_speed: fast
  rows: 16
  cols: 24
  well_depth_mm: 11.4
  offset_x_mm: 2.25
  offset_y_mm: 2.25
  spacing_x_mm: 4.5
  spacing_y_mm: 4.5
  well_volume_ul: 130.0
  dead_volume_ul: 6.5
  dead_volume_status: placeholder
  well_diameter_mm: 3.5
  well_geometry: square
  disposable_tip_capacity_ul: 10.0
  tip_definition_id: ''
  supported_tip_ids: []
  model_3d: /labware-assets/01KD4PYY7N4EG0E22P3QP1RHB9/384_Greiner_781091_PS_uclear.gltf
  can_mount: false
  can_be_mounted: false
- id: lw-4914769d0af7
  name: 384 V11 ST10 Tip Box 10734.102
  kind: sbs_plate
  vendor: ''
  catalog_number: ''
  description: Tip-rack aperture diameter 3.3 mm derived from the existing Onshape/PTC
    CAD model labware/editor_assets/lw-4914769d0af7/ST_Tip_Box.gltf (SHA256 0a9dfef973ae4266042b73614536132d693dc592135c3eccb270d6aa2b082fb5).
    Circle fits across all 384 apertures on 2026-10-07; model-derived geometry, not
    a physical measurement or hardware qualification. Existing catalog rack height
    and teachpoint offsets are unchanged.
  base_class: tip_box
  wells: 384
  length_mm: 127.76
  width_mm: 85.48
  height_mm: 50.0
  stack_height_mm: 0.0
  gripper_offset_mm: 10.0
  lid_gripper_offset_mm: null
  empty_check_offset_mm: null
  shim_thickness_mm: 0.0
  can_be_sealed: false
  sealed_height_mm: 0.0
  sealed_stacking_height_mm: 0.0
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

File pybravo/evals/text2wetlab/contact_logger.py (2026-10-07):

"""Annotate the pinned OT-2 run log with trusted dispense-position evidence.

The dataset's logger records well identities but drops the location height.
This wrapper runs that exact logger and adds a Boolean only when the simulator's
raw dispense location is at or above the destination well rim. It does not
change the pinned event order, quantities, or labware identities. The annotation
is a narrow noncontact signal for local carryover review, not an assertion that
the overall protocol is ready for a physical robot.
"""

from __future__ import annotations

import importlib.util
import json
import math
import sys
from pathlib import Path


def _at_or_above_well_rim(payload: dict) -> bool | None:
    location = payload.get("location")
    try:
        well = location.labware
        if hasattr(well, "as_well"):
            well = well.as_well()
        z = float(location.point.z)
        rim_z = float(well.top().point.z)
    except (AttributeError, TypeError, ValueError):
        return None
    if not math.isfinite(z) or not math.isfinite(rim_z):
        return None
    return z >= rim_z - 1e-6


def record(logger_path: Path, protocol_path: Path, labware_dir: Path) -> dict:
    spec = importlib.util.spec_from_file_location("pinned_text2wetlab_runlog", logger_path)
    if spec is None or spec.loader is None:
        raise RuntimeError(f"Could not load pinned run logger: {logger_path}")
    module = importlib.util.module_from_spec(spec)
    spec.loader.exec_module(module)
    original_parse = module.parse

    def annotated_parse(text: str, payload: dict) -> dict | None:
        event = original_parse(text, payload)
        if event is not None and event.get("kind") == "dispense":
            evidence = _at_or_above_well_rim(payload)
            if evidence is not None:
                event["at_or_above_well_rim"] = evidence
        return event

    module.parse = annotated_parse
    result = module.main(str(protocol_path), str(labware_dir))
    if not isinstance(result, dict):
        raise RuntimeError("Pinned run logger returned no result object")
    return result


def main(argv: list[str]) -> int:
    if len(argv) != 5:
        raise SystemExit("usage: contact_logger.py PINNED_LOGGER PROTOCOL LABWARE_DIR OUTPUT")
    _, logger, protocol, labware_dir, output = argv
    result = record(Path(logger), Path(protocol), Path(labware_dir))
    Path(output).write_text(json.dumps(result), encoding="utf-8")
    return 0


if __name__ == "__main__":
    raise SystemExit(main(sys.argv))

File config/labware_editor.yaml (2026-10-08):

# dead_volume_ul values are unreviewed review placeholders; see
# docs/labware_dead_volume_review.md before using them for a protocol.
version: 1
labware_types:
- labware_type_id: lw-3918306f45b8
  name: 1536 Labcyte LP-0400 LDV
  kind: sbs_plate
  vendor: ''
  catalog_number: ''
  description: ''
  base_class: microplate
  wells: 1536
  plate_dimensions_mm:
    length_mm: 127.76
    width_mm: 85.48
    height_mm: 10.5
  plate_properties:
    robot_gripper_offset_mm: 1.0
    empty_check_offset_mm: null
    thickness_mm: 10.48
    stacking_thickness_mm: 9.8
    shim_thickness_mm: null
    can_be_sealed: true
    sealed_thickness_mm: 10.5
    sealed_stacking_thickness_mm: 9.3
    can_have_lid: false
    lidded_thickness_mm: null
    lidded_stacking_thickness_mm: null
    lid_resting_height_mm: null
    lid_departure_height_mm: null
    lower_plate_at_labeler: false
    can_mount: false
    can_be_mounted: false
    max_robot_handling_speed: fast
    filter_tip_pin_tool_length_mm: null
    filter_channel_resting_depth_mm: null
    requires_insert: None
  well_dimensions_mm:
    rows: 32
    cols: 48
    volume_ul: 5.5
    dead_volume_ul: 0.3
    dead_volume_status: placeholder
    depth_mm: 5.2
    diameter_mm: 1.7
    offset_x_mm: 3.375
    offset_y_mm: 3.375
    spacing_x_mm: 2.25
    spacing_y_mm: 2.25
    well_geometry: 2
    well_bottom_shape: 2
    tip_source: agilent
    disposable_tip_capacity_ul: 10
    disposable_tip_length_mm: null
  pf400: {}
  planar_motor: {}
  labware_class_ids:
  - 01KD4PKQ8DFP12QWDM29CQWZ8A
  model_3d:
    url: /labware-assets/lw-3918306f45b8/1536_Labcyte_LP-0400_LDV.gltf
    filename: 1536_Labcyte_LP-0400_LDV.gltf
    format: gltf
  tip_definition_id: ''
  supported_tip_ids: []
- labware_type_id: lw-34358f93e2a0
  name: 384 CellVis 1.5H
  kind: sbs_plate
  vendor: Cellvis
  catalog_number: P384-1.5H-N
  description: ''
  base_class: microplate
  wells: 384
  plate_dimensions_mm:
    length_mm: 127.6
    width_mm: 85.6
    height_mm: 14.33
  plate_properties:
    robot_gripper_offset_mm: 8
    empty_check_offset_mm: null
    thickness_mm: 14.33
    stacking_thickness_mm: null
    shim_thickness_mm: null
    can_be_sealed: false
    sealed_thickness_mm: null
    sealed_stacking_thickness_mm: null
    can_have_lid: true
    lidded_thickness_mm: 16.8
    lidded_stacking_thickness_mm: 17.7
    lid_resting_height_mm: 6.8
    lid_departure_height_mm: 11
    lid_geometry:
      model: manufacturer_exterior_envelope
      length_mm: 127.15
      width_mm: 85.05
      height_mm: 10.0
      seated_bottom_mm: 6.8
      source: https://www.cellvis.com/images/glass_bottom_plate_384_well_size.png
      source_document: docs/media/cellvis-384-plate-lid-dimensions.png
      source_sha256: 3ca5ca8dcf5f6aff0c44d32f66796c478ce66119c149fbcc250cef7d0f423985
      source_note: Official Cellvis dimension diagram supplied by user; seated bottom = 16.8 - 10.0 mm.
      limitations:
      - Wall thickness, internal clearance and corner chamfers are not dimensioned.
    lower_plate_at_labeler: false
    can_mount: false
    can_be_mounted: false
    max_robot_handling_speed: fast
    filter_tip_pin_tool_length_mm: null
    filter_channel_resting_depth_mm: null
    requires_insert: None
    robot_lid_gripper_offset_mm: 0.5
  well_dimensions_mm:
    dead_volume_ul: 5.0
    dead_volume_status: placeholder
    rows: 16
    cols: 24
    depth_mm: 11.38
    diameter_mm: 3.3
    offset_x_mm: 2.25
    offset_y_mm: 2.25
    spacing_x_mm: 4.5
    spacing_y_mm: 4.5
    well_geometry: 2
  pf400: {}
  planar_motor: {}
  labware_class_ids:
  - 01KD4PKQ8DFP12QWDM29CQWZ8A
  tip_definition_id: ''
  supported_tip_ids: []
  model_3d: /labware-assets/lw-34358f93e2a0/Cellvis_P384_1.5H_N.glb
- kind: sbs_plate
  name: 384 Labcyte PP0200 PP sq flt
  vendor: Beckman
  catalog_number: 001-14622
  description: Echo(R) Qualified 384-Well Polypropylene Microplate, Clear, Sterile,
    Surface-treated with Amine Coating
  base_class: microplate
  labware_class_ids:
  - 01KD4PKQ8DFP12QWDM29CQWZ8A
  wells: 384
  well_type: ''
  plate_dimensions_mm:
    length_mm: 127.76
    width_mm: 85.48
    height_mm: 14.4
  plate_properties:
    robot_gripper_offset_mm: 7
    empty_check_offset_mm: null
    thickness_mm: 14.4
    stacking_thickness_mm: 13.6
    shim_thickness_mm: 4
    can_be_sealed: true
    sealed_thickness_mm: 0
    sealed_stacking_thickness_mm: 0
    can_have_lid: true
    lidded_thickness_mm: 16.5
    lidded_stacking_thickness_mm: 14.5
    lid_resting_height_mm: 9.5
    lid_departure_height_mm: 8.5
    lower_plate_at_labeler: true
    can_mount: true
    can_be_mounted: true
    max_robot_handling_speed: fast
    filter_tip_pin_tool_length_mm: 0
    filter_channel_resting_depth_mm: 0
    requires_insert: None
    robot_lid_gripper_offset_mm: null
  well_dimensions_mm:
    diameter_mm: 3.5
    depth_mm: 11.4
    volume_ul: 130
    dead_volume_ul: 6.5
    dead_volume_status: placeholder
    spacing_x_mm: 4.5
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

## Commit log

2026-09-27 Keep the tips-on fast approach and connect-time head apply AssayMAP-only
    Two changes in the AssayMAP work reached every head, and both alter what a
    96LT or 384 Darwin install does today:
    - TipsOnTask on a controller without tip_force_jog (Darwin, simulation)
    replaced the single force-limited jog with a fast unforced move to 25 mm
    above the seat followed by a bounded press. That drops force protection
    for most of the descent. Standard heads now keep the original jog at
    25 mm/s / 250 mm/s^2 under current control for the whole travel; only
    is_assaymap takes the two-move press that was verified on that head.
    - Bravo.connect() pushed the profile head type onto the controller for any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
2026-09-27 Apply the profile head on connect for every head; fit tips-off W to the limits
    Re-enables the connect-time head apply for all heads, so a Darwin instrument
    no longer runs W on the placeholder calibration until someone remembers
    POST /api/change_head. Applying the head also installs the per-head W
    software limits, and the shipped Darwin profiles carried tips_off_w_position
    values outside them, which would have refused Tips Off pre-flight:
    96LT, Claptrap, Flowby -15.0 / -35.0 -> -9.0 (HT_96_D_200 min -9.186)
    default, simulation -11.0 -> -9.3 (HT_384_D_70 min -9.314)
    SafetyConfig default -11.0 -> -9.3
    -9.0 is the value the LT200 tip-box override alre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
    [96LT.yaml, Claptrap.yaml, Flowby.yaml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]
2026-09-27 Fix lint on the AssayMAP tests; keep cartridge identity through the Tip Editor
    Lint: ruff reported 12 errors in five new test files (import order, unused
    imports, and `l` as a comprehension variable). Autofixed the imports and
    renamed the variables. `ruff check .` is clean again, so the Lint CI job
    passes.
    Tip Editor: _normalize_tip_payload and TipDefinitionRequest never learned the
    kind and overflow_ul fields added with the AssayMAP work, so any create or
    patch through /api/tips rewrote the row without them. A label edit turned
    the cartridge definition back into a plain tip, and Tips On would then zero
    W during the next cartridge mount, expelling whatever the syringes held.
    Both now carry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
    [96am.yaml]
2026-10-05 Reskin Bravo URDF with realistic materials and grouped deck colors
    [bravo_brand_emblem.stl, bravo_carriage_cover.stl, bravo_carriage_seam.stl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]
2026-10-06 Add reviewable plate dead-volume placeholders
2026-10-06 Rank planning classes by calibration-point proximity
2026-10-07 Frame compiled preview and expose read-only node details
2026-10-07 Reject heat-shock recovery while block remains hot
2026-10-07 Add evidence-grounded OT-2 planning audits
2026-10-07 Repair OT-2 simulator failures with bounded local line patches
    [patch_repair.py]
2026-10-07 Carry source stage checks through Designer repairs
2026-10-07 Add catalog-grounded local Qwen repair for saved Designer drafts
2026-10-07 Ground generated intermediates and plan repair feedback
2026-10-07 Ground paper excerpts and harden local evaluation repairs
2026-10-07 Tighten RNA extraction rubric chronology and deck checks
    [rubric_audit.py]
2026-10-07 Add grounded scientific line repair experiment for Text2WetLab
2026-10-07 Ground Designer repairs in ready hardware pairings
2026-10-07 Tighten Text2WetLab safety and source-guided repairs
    [adapter.py, contact_logger.py, rubric_audit.py]
2026-10-07 Prevent exploratory duplicate steps in Qwen protocol prompts
    [adapter.py]
2026-10-07 Include decimal-named tube racks in OT-2 geometry context
2026-10-07 Reject unresolved draft corrections in generated protocols
    [adapter.py]
2026-10-07 Document source-grounded Text2WetLab coverage gaps
2026-10-07 Allow bounded multi-stage local-model line repairs
2026-10-07 Teach and validate supported OT-2 pipette loading API
2026-10-07 Add source-preserving simulated material ledger
2026-10-07 Bridge accepted plan quantities into cited ledger targets
2026-10-07 Experiment with staged local OT-2 action plans
2026-10-07 Bound staged ActionPlan model call count
2026-10-07 Bind staged source inventory to exact cited wells
2026-10-07 Scope phased citations and preserve bounded stage repairs
2026-10-07 Clarify staged reaction math and fresh-tip planning
2026-10-07 Bound simulated Zg travel and align docked gripper render
2026-10-07 Preflight staged reactions with cited model-authored math
2026-10-07 Lower rendered gripper dock pose by five millimeters
2026-10-07 Ground generated drafts in hardware catalogs and add visual walkthroughs
2026-10-07 Add SuperDex collision rehearsal and track fresh versus spent tips
    [planning.py]
2026-10-07 Prevent liquid tasks from targeting tip racks and preflight rack geometry
    [labware_catalog.snapshot.yaml, labware_editor.yaml, planning.py]
2026-10-07 Map liquid task anchors from mounted tips and plate geometry
2026-10-07 Remove explanatory boilerplate from plate selection
2026-10-07 Let liquid well pickers select a valid plate destination
2026-10-08 Align gripper grasp geometry and restore real liquid well depth
    [robot.urdf]
2026-10-08 Show covered-plate setup failures in a 3D obstruction popup
